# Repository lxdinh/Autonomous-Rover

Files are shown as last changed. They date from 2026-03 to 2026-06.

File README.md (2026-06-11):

# Autonomous Navigation Rover






**🏆 1st Place — UCSD ECE Design Competition (Nov–Dec 2025)** · fastest pathfinding of 13 teams

> Vision-guided autonomous ground rover on a custom ESP32-S3 PCB. An ArduCAM
> OV2640 camera runs on-board RGB565 obstacle detection, an MPU6050 IMU damps the
> heading, and an L298N H-bridge drives the wheels — coordinated by a lightweight
> **FORWARD → STOP → AVOID** state machine. Everything runs on the
> microcontroller.

## Highlights

- **Custom 2-layer, 4×4 in PCB** (KiCad) integrating the ESP32-S3, OV2640,
  MPU6050, and L298N with a shared logic/motor power tree — schematic and
  Gerbers in [`hardware/`](hardware/).
- **From-scratch bare-metal drivers**, no vendor HAL: custom I²C (MPU6050),
  SPI-FIFO (ArduCAM), and LEDC-PWM (L298N) classes — 600+ lines of C++.
- **On-board vision:** per-frame red-blob detection over the middle image band,
  feeding a deterministic navigation state machine.

## Architecture

```mermaid
flowchart LR
  subgraph Sensing
    CAM[OV2640 camera<br/>SPI FIFO] --> DET[Red-blob detector<br/>RGB565, middle band]
    IMU[MPU6050<br/>I2C] --> YAW[Yaw-rate filter]
  end
  DET --> SM[Nav state machine<br/>FORWARD / STOP / AVOID]
  YAW --> MIX[Tank-drive mixer]
  SM --> MIX
  MIX --> MOT[L298N H-bridge<br/>LEDC PWM] --> W[Wheels]
```

### Navigation state machine

```mermaid
stateDiagram-v2
  [*] --> FORWARD
  FORWARD --> STOP: red band >= 20%
  STOP --> AVOID: held 200 ms and still blocked
  STOP --> FORWARD: obstacle cleared
  AVOID --> FORWARD: blob out of view
```

## Repository layout

```text
Autonomous-Rover/
├── src/
│   ├── main.cpp            # nav state machine + obstacle detection + cruise mixer
│   ├── Camera_SPI.h        # ArduCAM OV2640 over SPI FIFO (DMA buffer, BMP/RGB565)
│   ├── Sensor_I2C.h        # MPU6050 IMU (accel/gyro), bare-metal I2C
│   └── MotorDriver_PWM.h   # L298N via ESP32 LEDC PWM (Arduino core 2.x/3.x aware)
├── include/memorysaver.h   # ArduCAM camera-model selector (OV2640 Mini 2MP)
├── hardware/               # KiCad project, schematic (SVG), Gerbers
├── platformio.ini
└── README.md
```

## Hardware

| Subsystem | Part | Interface |
| --- | --- | --- |
| MCU | ESP32-S3 (DevKitC-1 class) | — |
| Camera | ArduCAM OV2640 Mini 2MP | SPI FIFO + I²C control |
| IMU | MPU6050 (accel + gyro) | I²C @ `0x68` |
| Motor driver | L298N dual H-bridge | 6 GPIO (2 PWM enables + 4 direction) |
| Power | 9 V motor pack + 3.3 V logic | common ground |

### Pin map (ESP32-S3)

| Function | GPIO | | Function | GPIO |
| --- | --- | --- | --- | --- |
| L298N ENA — left PWM | 40 | | I²C SDA | 15 |
| L298N ENB — right PWM | 39 | | I²C SCL | 17 |
| L298N IN1 / IN2 — left dir | 44 / 43 | | SPI SCK | 12 |
| L298N IN3 / IN4 — right dir | 42 / 41 | | SPI MISO | 13 |
| Camera CS | 10 | | SPI MOSI | 11 |

### Schematic

Rover schematic

## How obstacle detection works

Each captured frame is RGB565 (one 16-bit value per pixel). The detector scans
the **middle horizontal third** of the frame — where a head-on obstacle sits —
and flags a pixel as "red" when:

| Channel | Bits | Rule |
| --- | --- | --- |
| Red | 5 (0–31) | ≥ 22 |
| Green | 6 (0–63) | ≤ 14 |
| Blue | 5 (0–31) | ≤ 14 |

If **≥ 20 %** of the band's pixels pass, the frame is treated as blocked and the
state machine reacts. All thresholds are compile-time constants in
[`src/main.cpp`](src/main.cpp) — retune `RED_MIN_5BIT`, `GREEN_MAX_6BIT`,
`BLUE_MAX_5BIT`, and `DETECTION_THRESHOLD_PERCENT` for your obstacle color and
lighting.

## Build & flash

Built with **[PlatformIO](https://platformio.org/)** (ESP32-S3 / Arduino
framework). The ArduCAM library is pulled from the PlatformIO registry
automatically; the camera model is selected via the `-DOV2640_MINI_2MP` build
flag in [`platformio.ini`](platformio.ini).

```bash
# from the repo root
pio run                        # compile
pio run -t upload              # flash (board on its native USB port)
pio device monitor -b 115200   # serial @ 115200
```

**Arduino IDE** users: install the **ArduCAM** library, provide a `memorysaver.h`
with `#define OV2640_MINI_2MP`, select an ESP32-S3 board with **USB CDC On Boot:
Enabled**, and build `src/main.cpp`.

## Design notes & tuning

- **Motor duty is capped** to `MOTOR_MAX_DUTY_PCT` (85 %) so that simultaneous
  acceleration on a sagging 9 V pack does not brown out the 3.3 V logic rail.
- **Camera resolution is read from the BMP header** on every capture, so the
  pipeline is robust to QVGA/QCIF differences across ArduCAM firmware revisions.
- **Heading hold:** the MPU6050 yaw-rate currently applies gentle equal-wheel
  damping. Promoting it to a *differential* correction (opposite sign per wheel)
  is the natural next step for tighter straight-line tracking; the mixer already
  exposes a symmetric correction term to build on.

## License

MIT — see [LICENSE](LICENSE). Firmware and hardware authored for the UCSD ECE
Design Competition.

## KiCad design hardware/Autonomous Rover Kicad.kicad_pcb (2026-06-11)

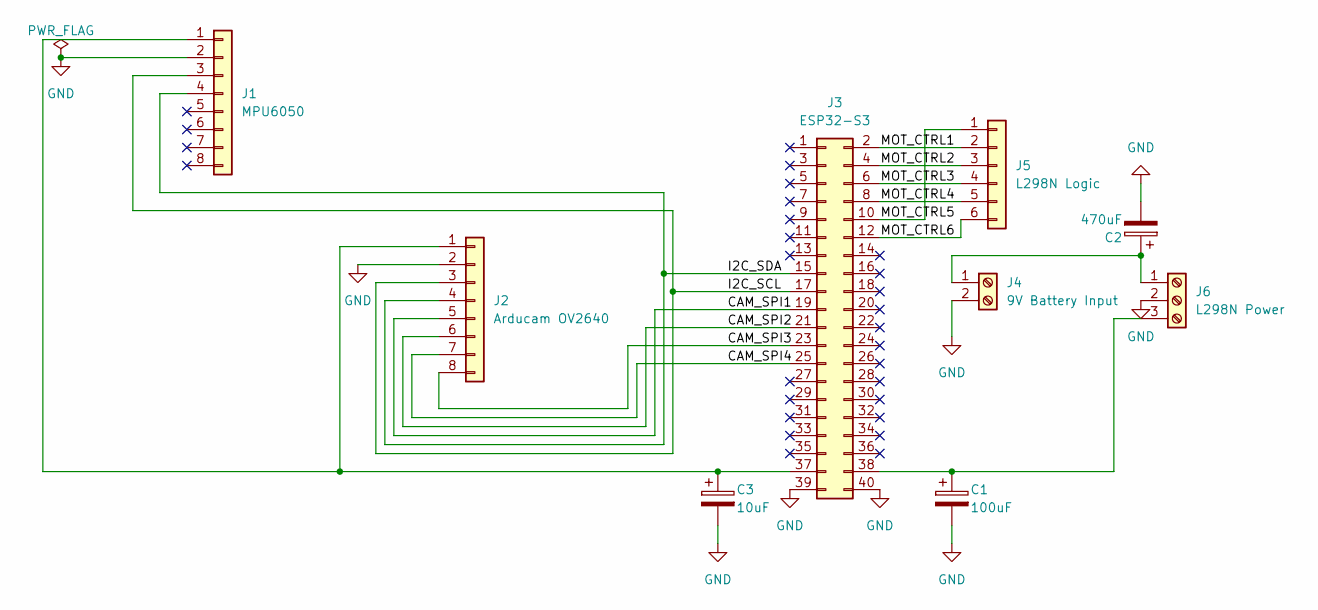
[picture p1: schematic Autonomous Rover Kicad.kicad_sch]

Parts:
C1: 100uF; CP_Radial_D6.3mm_P2.50mm
C2: 470uF; CP_Radial_D8.0mm_P3.50mm
C3: 10uF; CP_Radial_D5.0mm_P2.50mm
J1: MPU6050; PinHeader_1x08_P2.54mm_Vertical
J2: Arducam OV2640; PinHeader_1x08_P2.54mm_Vertical
J3: ESP32-S3; PinHeader_2x20_P2.54mm_Vertical
J4: 9V Battery Input; TerminalBlock_Phoenix_PT-1,5-2-3.5-H_1x02_P3.50mm_Horizontal
J5: L298N Logic; PinHeader_1x06_P2.54mm_Vertical
J6: L298N Power; TerminalBlock_Phoenix_PT-1,5-3-3.5-H_1x03_P3.50mm_Horizontal

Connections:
/CAM_SPI1: J2.5, J3.19
/CAM_SPI2: J2.6, J3.21
/CAM_SPI3: J2.8, J3.23
/CAM_SPI4: J2.7, J3.25
/I2C_SCL: J1.3, J2.3, J3.17
/I2C_SDA: J1.4, J2.4, J3.15
/MOT_CTRL1: J3.2, J5.2
/MOT_CTRL2: J3.4, J5.3
/MOT_CTRL3: J3.6, J5.4
/MOT_CTRL4: J3.8, J5.5
/MOT_CTRL5: J3.10, J5.1
/MOT_CTRL6: J3.12, J5.6
GND: C1.2, C2.2, C3.2, J1.2, J2.2, J3.39, J3.40, J4.2, J6.2
unnamed: C3.1, J1.1, J2.1, J3.37
unnamed: C1.1, J3.38, J6.3
unnamed: C2.1, J4.1, J6.1

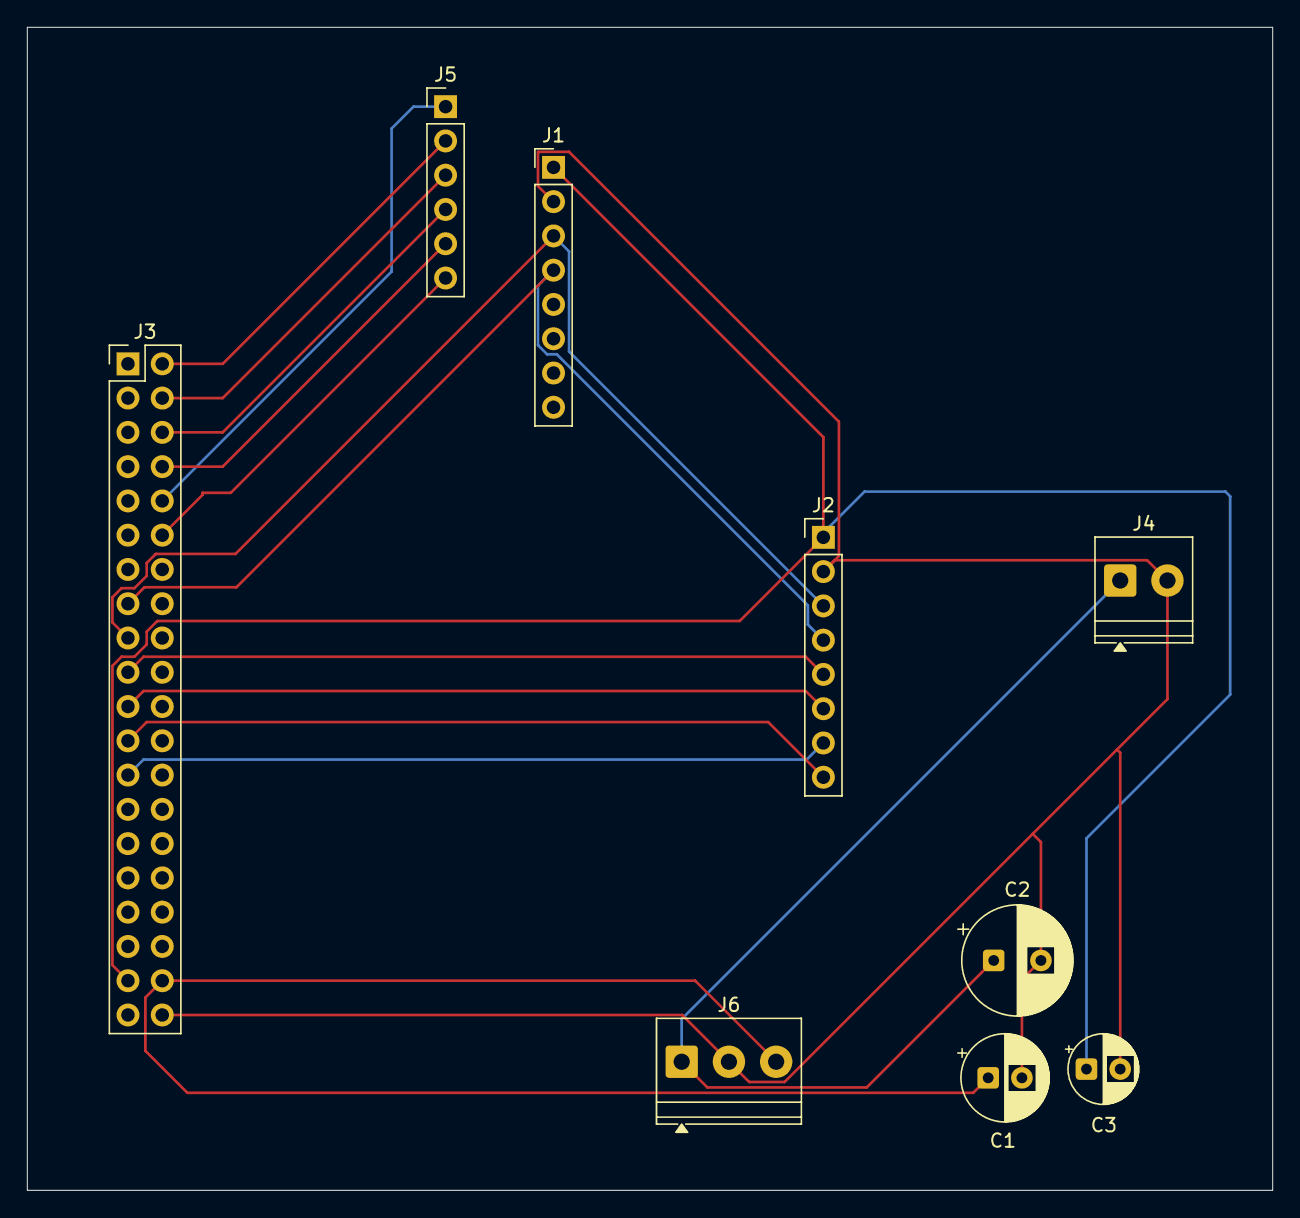
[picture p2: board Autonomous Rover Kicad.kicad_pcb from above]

Board: 2 copper layers, 92.3 x 86.2 mm, 9 parts (0 on the bottom side), 16 nets.

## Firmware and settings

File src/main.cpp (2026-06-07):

/**
 * ESP32-S3 rover — camera obstacle avoidance using ArduCAM OV2640 (SPI FIFO + I2C sensor).
 * Wire @ SDA/SCL talks to MPU6050 (0x68) and OV2640 regs through the ArduCAM bridge;
 * SPI pushes CS low and bursts pixel data from the camera FIFO after each capture.
 */

#include <Arduino.h>

#if defined(CONFIG_IDF_TARGET_ESP32S3) || defined(ARDUINO_ESP32S3_DEV) || \
    defined(ARDUINO_ESP32S3)
#include <driver/gpio.h>
#endif

#include <SPI.h>
#include <Wire.h>

#include "MotorDriver_PWM.h"
#include "Sensor_I2C.h"
#include "Camera_SPI.h"

// --- Pins (KiCad / ESP32-S3) ---
static const uint8_t PIN_IN1 = 44;
static const uint8_t PIN_IN2 = 43;
static const uint8_t PIN_IN3 = 42;
static const uint8_t PIN_IN4 = 41;
static const uint8_t PIN_ENA = 40;
static const uint8_t PIN_ENB = 39;
static const uint8_t PIN_SDA = 15;
static const uint8_t PIN_SCL = 17;
static const uint8_t PIN_SCK = 12;
static const uint8_t PIN_MISO = 13;
static const uint8_t PIN_MOSI = 11;
static const uint8_t PIN_CAM_CS = 10;

// --- Obstacle detection (RGB565 "red blob" in middle horizontal band) ---
// Each pixel is 16 bits: 5 bits R, 6 bits G, 5 bits B (no separate bytes — packed in one uint16).
#define DETECTION_THRESHOLD_PERCENT 20  // call it an obstacle if >= this % of band pixels look "red"
#define RED_MIN_5BIT 22                 // R must be at least this (0–31 scale)
#define GREEN_MAX_6BIT 14               // G must be at most this (0–63 scale)
#define BLUE_MAX_5BIT 14                // B must be at most this (0–31 scale)

// --- Driving / timing ---
static const int16_t CRUISE_BASE_SPEED = 130;
static const int16_t TURN_LEFT_WHEEL = 150;
static const int16_t TURN_RIGHT_WHEEL = -150;
static const uint32_t SENSOR_MS = 20;
static const uint32_t OBSTACLE_CHECK_MS = 40;
static const uint32_t SERIAL_STATUS_MS = 400;
// Don't print faster than this — still feels "live" but won't overwhelm Serial Monitor.
static const uint32_t CAMERA_DEBUG_MIN_MS = 150;
// How long we sit in STOP (motors off) before we start AVOID turn — easy to show on demo day.
static const uint32_t STOP_HOLD_MS = 200;

SensorI2C imu(PIN_SDA, PIN_SCL);
MotorDriverPWM motors(PIN_ENA, PIN_ENB, PIN_IN1, PIN_IN2, PIN_IN3, PIN_IN4);
CameraSPI cam(PIN_CAM_CS);

uint32_t lastSens = 0;
uint32_t lastObs = 0;
uint32_t lastSerial = 0;
uint32_t lastCameraPrint = 0;

float yawRateFiltered = 0.0f;

// Navigation state machine (FORWARD -> STOP -> AVOID -> FORWARD)
enum RoverState : uint8_t { STATE_FORWARD = 0, STATE_STOP = 1, STATE_AVOID = 2 };
static RoverState roverState = STATE_FORWARD;
static uint32_t stopStateEnteredMs = 0;

bool isObstacleDetected = false;
static float lastRedBandPercent = 0.0f;  // for Serial debug

static int16_t computeLeft(int16_t base, float brightnessErr, float yawDps) {
  int32_t v = base + (int32_t)(brightnessErr * 0.8f) - (int32_t)(yawDps * 6.0f);
  if (v > 200) v = 200;
  if (v < -200) v = -200;
  return (int16_t)v;
}

static int16_t computeRight(int16_t base, float brightnessErr, float yawDps) {
  int32_t v = base - (int32_t)(brightnessErr * 0.8f) - (int32_t)(yawDps * 6.0f);
  if (v > 200) v = 200;
  if (v < -200) v = -200;
  return (int16_t)v;
}

/**
 * Grab one frame from the ArduCAM FIFO (SPI), then count "red-looking" pixels in the
 * middle horizontal band (middle third of rows). Returns false if capture failed.
 *
 * RGB565 math (one 16-bit value per pixel):
 *   bits 15..11 -> Red   (5 bits): shift right by 11, then mask 0x1F
 *   bits 10..5  -> Green (6 bits): shift right by 5,  mask 0x3F
 *   bits 4..0   -> Blue  (5 bits): mask 0x1F (no shift)
 * We compare those to RED_MIN / GREEN_MAX / BLUE_MAX to catch "mostly red" obstacles.
 */
bool detectObstacle(CameraSPI &camera, bool &outObstacle, float &outRedPercent) {
  outObstacle = false;
  outRedPercent = 0.0f;

  if (!camera.captureFrameQCIF_DMA()) {
    Serial.println("[detectObstacle] FIFO capture failed");
    return false;
  }

  const uint16_t *pixels = (const uint16_t *)camera.frameBuffer();
  uint16_t imgW = camera.width();
  uint16_t imgH = camera.height();
  if (!pixels || imgW == 0 || imgH < 3) {
    return false;
  }

  // Middle horizontal band: rows [H/3 .. 2H/3) — where we expect obstacles in front of the rover.
  uint16_t rowStart = imgH / 3;
  uint16_t rowEnd = (2u * imgH) / 3;

  uint32_t redCount = 0;
  uint32_t totalInBand = 0;

  for (uint16_t y = rowStart; y < rowEnd; y++) {
    const uint16_t *row = pixels + (size_t)y * imgW;
    for (uint16_t x = 0; x < imgW; x++) {
      uint16_t p = row[x];
      // Split RGB565 into R, G, B using the bit layout above.
      uint8_t r = (uint8_t)((p >> 11) & 0x1F);
      uint8_t g = (uint8_t)((p >> 5) & 0x3F);
      uint8_t b = (uint8_t)(p & 0x1F);

      totalInBand++;
      if (r >= RED_MIN_5BIT && g <= GREEN_MAX_6BIT && b <= BLUE_MAX_5BIT) {
        redCount++;
      }
    }
  }

  float pct = 0.0f;
  if (totalInBand > 0) {
    pct = 100.0f * (float)redCount / (float)totalInBand;
  }
  outRedPercent = pct;
  outObstacle = (pct >= (float)DETECTION_THRESHOLD_PERCENT);
  return true;
}

#if defined(CONFIG_IDF_TARGET_ESP32S3) || defined(ARDUINO_ESP32S3_DEV) || \
    defined(ARDUINO_ESP32S3)
static void roverPrepareL298nGpio(void) {
  gpio_reset_pin((gpio_num_t)PIN_ENB);
  gpio_reset_pin((gpio_num_t)PIN_ENA);
  gpio_reset_pin((gpio_num_t)PIN_IN4);
  gpio_reset_pin((gpio_num_t)PIN_IN3);
  gpio_reset_pin((gpio_num_t)PIN_IN2);
  gpio_reset_pin((gpio_num_t)PIN_IN1);
}
#endif

void setup() {
  Serial.begin(115200);
  delay(300);
  Serial.println("\n=== rover boot (ArduCAM obstacle + state machine) ===");

#if defined(CONFIG_IDF_TARGET_ESP32S3) || defined(ARDUINO_ESP32S3_DEV) || \
    defined(ARDUINO_ESP32S3)
  roverPrepareL298nGpio();
#endif

  // Shared I2C bus: MPU6050 @ 0x68, OV2640 sensor regs via ArduCAM @ 0x30 (7-bit addresses).
  Wire.begin(PIN_SDA, PIN_SCL);
  if (!imu.begin()) {
    Serial.println("IMU init failed");
  }

  SPI.begin(PIN_SCK, PIN_MISO, PIN_MOSI, PIN_CAM_CS);
  if (!cam.begin()) {
    Serial.println("[fatal] camera init failed");
  }

  motors.begin();

  Serial.println("States: FORWARD -> STOP (red >= threshold) -> AVOID (turn) -> FORWARD");
}

void loop() {
  uint32_t now = millis();

  if (now - lastSens >= SENSOR_MS) {
    lastSens = now;
    float gz = imu.gyroZdps();
    yawRateFiltered = 0.85f * yawRateFiltered + 0.15f * gz;
  }

  if (now - lastObs >= OBSTACLE_CHECK_MS) {
    lastObs = now;
    bool obs = false;
    float redPct = 0.0f;
    if (detectObstacle(cam, obs, redPct)) {
      isObstacleDetected = obs;
      lastRedBandPercent = redPct;

      if (now - lastCameraPrint >= CAMERA_DEBUG_MIN_MS) {
        lastCameraPrint = now;
        Serial.print("Camera: red pixels ~ ");
        Serial.print(redPct, 1);
        Serial.print("% (threshold ");
        Serial.print(DETECTION_THRESHOLD_PERCENT);
        Serial.println("%)  ");
      }

      if (obs && roverState == STATE_FORWARD) {
        roverState = STATE_STOP;
        stopStateEnteredMs = now;  // use the loop's timestamp; a fresh millis()
                                   // here is > now and underflows the unsigned
                                   // (now - stopStateEnteredMs) hold check below.
        Serial.println("State -> STOP (cut motors briefly)");
      }
    }
  }

  float err = 0.0f;
  int16_t leftCruise = computeLeft(CRUISE_BASE_SPEED, err, yawRateFiltered);
  int16_t rightCruise = computeRight(CRUISE_BASE_SPEED, err, yawRateFiltered);

  switch (roverState) {
    case STATE_FORWARD:
      motors.setTankDrive(leftCruise, rightCruise);
      break;

    case STATE_STOP:
      motors.stop();
      if (!isObstacleDetected) {
        roverState = STATE_FORWARD;
        Serial.println("State -> FORWARD (obstacle cleared while stopped)");
      } else if ((now - stopStateEnteredMs) >= STOP_HOLD_MS) {
        roverState = STATE_AVOID;
        Serial.println("State -> AVOID (turn right to get blob out of view)");
      }
      break;

    case STATE_AVOID:
      motors.setTankDrive(TURN_LEFT_WHEEL, TURN_RIGHT_WHEEL);
      if (!isObstacleDetected) {
        roverState = STATE_FORWARD;
        Serial.println("State -> FORWARD (blob gone)");
      }
      break;

    default:
      roverState = STATE_FORWARD;
      break;
  }

  if (now - lastSerial >= SERIAL_STATUS_MS) {
    lastSerial = now;
    Serial.print("[nav] state=");
    switch (roverState) {
      case STATE_FORWARD:
        Serial.print("FORWARD");
        break;
      case STATE_STOP:
        Serial.print("STOP");
        break;
      case STATE_AVOID:
        Serial.print("AVOID");
        break;
      default:
        Serial.print("?");
        break;
    }
    Serial.print("  lastRed=");
    Serial.print(lastRedBandPercent, 1);
    Serial.println("%");
  }
}

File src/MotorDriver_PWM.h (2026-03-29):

/**
 * MotorDriver_PWM.h
 * Simple L298N wrapper for ESP32 LEDC PWM on enable pins.
 * IN pins are digital; ENA/ENB use LEDC only (never analogWrite()).
 *
 * Core 2.x: ledcSetup + ledcAttachPin + ledcWrite(channel).
 * Core 3.x: ledcAttach(pin) + ledcWrite(pin) — picked automatically via esp_arduino_version.h.
 *
 * ESP32-S3: GPIO39–44 are valid outputs; ENA/ENB get normal LEDC PWM (no dedicated
 * “motor” pins). Note: GPIO39–42 are the chip’s default JTAG (MTCK/MTDO/MTDI/MTMS);
 * with motors on those nets, turn off JTAG in firmware or your debugger may fight
 * the L298N. IN1/IN2 on 43–44 are outside that block.
 *
 * NOTE: Duty is scaled assuming a ~9V nominal battery pack. Fresh cells read
 * higher (~9.6V) but under load the pack sags — we cap effective PWM so the
 * motors don't brown out the ESP32 rail when both sides spike. Tune MAX_DUTY_PCT.
 */
#ifndef MOTOR_DRIVER_PWM_H
#define MOTOR_DRIVER_PWM_H

#include <Arduino.h>

#ifndef __has_include
#define __has_include(x) 0
#endif
#if __has_include("esp_arduino_version.h")
#include "esp_arduino_version.h"
#endif

// Arduino-ESP32 3.0+ uses pin-based LEDC; 2.x uses channel + ledcAttachPin.
#if defined(ESP_ARDUINO_VERSION_MAJOR) && (ESP_ARDUINO_VERSION_MAJOR >= 3)
#define MOTOR_LEDC_USE_PIN_API 1
#else
#define MOTOR_LEDC_USE_PIN_API 0
#endif

// 9V pack: leave headroom so simultaneous accel doesn't dip logic supply too hard
#ifndef MOTOR_MAX_DUTY_PCT
#define MOTOR_MAX_DUTY_PCT 85  // percent of LEDC resolution range
#endif

class MotorDriverPWM {
 public:
  MotorDriverPWM(uint8_t pinEnA, uint8_t pinEnB, uint8_t pinIn1, uint8_t pinIn2,
                 uint8_t pinIn3, uint8_t pinIn4, uint32_t pwmFreqHz = 5000,
                 uint8_t pwmBits = 8)
      : _ena(pinEnA),
        _enb(pinEnB),
        _in1(pinIn1),
        _in2(pinIn2),
        _in3(pinIn3),
        _in4(pinIn4),
        _freq(pwmFreqHz),
        _bits(pwmBits),
        _chA(0),
        _chB(1) {}

  void begin() {
    pinMode(_in1, OUTPUT);
    pinMode(_in2, OUTPUT);
    pinMode(_in3, OUTPUT);
    pinMode(_in4, OUTPUT);

    pwmAttachEnables();

#if MOTOR_LEDC_USE_PIN_API
    Serial.println("[MotorDriver] L298N PWM: core 3.x (ledcAttach + ledcWrite pin)");
#else
    Serial.println("[MotorDriver] L298N PWM: core 2.x (ledcSetup + ledcAttachPin + channel)");
#endif

    stop();
  }

  /** speed: -255..255-ish, sign = direction */
  void setLeftMotor(int16_t speed) {
    bool fwd = speed >= 0;
    uint16_t mag = (uint16_t)abs(speed);
    mag = scaleDuty(mag);
    digitalWrite(_in1, fwd ? HIGH : LOW);
    digitalWrite(_in2, fwd ? LOW : HIGH);
    pwmWriteEna(mag);
  }

  void setRightMotor(int16_t speed) {
    bool fwd = speed >= 0;
    uint16_t mag = (uint16_t)abs(speed);
    mag = scaleDuty(mag);
    digitalWrite(_in3, fwd ? HIGH : LOW);
    digitalWrite(_in4, fwd ? LOW : HIGH);
    pwmWriteEnb(mag);
  }

  void setTankDrive(int16_t left, int16_t right) {
    setLeftMotor(left);
    setRightMotor(right);
  }

  void stop() {
    digitalWrite(_in1, LOW);
    digitalWrite(_in2, LOW);
    digitalWrite(_in3, LOW);
    digitalWrite(_in4, LOW);
    pwmWriteEna(0);
    pwmWriteEnb(0);
  }

 private:
  uint8_t _ena, _enb, _in1, _in2, _in3, _in4;
  uint32_t _freq;
  uint8_t _bits;
  uint8_t _chA, _chB;  // legacy core: LEDC channel indices for ENA/ENB

  void pwmAttachEnables() {
#if MOTOR_LEDC_USE_PIN_API
    if (!ledcAttach(_ena, (double)_freq, _bits)) {
      Serial.println("[MotorDriver] ledcAttach ENA failed");
    }
    if (!ledcAttach(_enb, (double)_freq, _bits)) {
      Serial.println("[MotorDriver] ledcAttach ENB failed");
    }
#else
    ledcSetup(_chA, _freq, _bits);
    ledcSetup(_chB, _freq, _bits);
    ledcAttachPin(_ena, _chA);
    ledcAttachPin(_enb, _chB);
#endif
  }

  void pwmWriteEna(uint16_t duty) {
#if MOTOR_LEDC_USE_PIN_API
    ledcWrite(_ena, duty);
#else
    ledcWrite(_chA, duty);
#endif
  }

  void pwmWriteEnb(uint16_t duty) {
#if MOTOR_LEDC_USE_PIN_API
    ledcWrite(_enb, duty);
#else
    ledcWrite(_chB, duty);
#endif
  }

  uint16_t scaleDuty(uint16_t raw) {
    uint32_t maxVal = (1u << _bits) - 1u;
    uint32_t cap = (maxVal * (uint32_t)MOTOR_MAX_DUTY_PCT) / 100u;
    if (raw > maxVal) raw = (uint16_t)maxVal;
    uint32_t out = (raw * cap) / maxVal;
    return (uint16_t)out;
  }
};

#endif

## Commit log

2026-03-29 Initial release
    [Autonomous Rover Kicad-B_Cu.gbr, Autonomous Rover Kicad-B_Mask.gbr, Autonomous Rover Kicad-B_Paste.gbr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]
2026-03-29 Embed schematic image into README
2026-06-07 Fix firmware build + harden project (CI, docs, license)
    The committed firmware did not compile; it now builds clean for the ESP32-S3,
    verified locally with `pio run` (RAM 6.2%, Flash 9.2%).
    - Camera_SPI.h: make pixelDataPtr() const so the const frameBuffer() overload
    compiles. This was a hard error (passing 'const CameraSPI' as 'this' discards
    qualifiers) that broke the entire build on a standard PlatformIO toolchain.
    - main.cpp: fix unsigned underflow in the FORWARD->STOP hold timer. It set
    stopStateEnteredMs with a fresh millis() taken after `now`, so
    (now - stopStateEnteredMs) underflowed and the rover skipped its 200 ms stop
    and jumped straight to AVOID. Use the loop's `now` t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
    [Camera_SPI.h, main.cpp]
2026-06-11 Clean up schematic: ERC 0, net labels, decoupling caps
    KiCad ERC now passes with 0 violations (was 29 - all unannotated unused pins
    plus a missing power flag), verified with kicad-cli 9.0.
    - Add no-connect flags to the 28 intentionally-unused module pins (MPU6050
    J1.5-8 and the unused ESP32/J3 GPIOs).
    - Add a PWR_FLAG on GND so ERC knows the rail is externally powered.
    - Name the nets: +5V, +3V3, VMOTOR, I2C_SDA, I2C_SCL, CAM_SPI1-4,
    MOT_CTRL1-6 (were auto-named Net-Jx-Pin_y).
    - Add bulk decoupling: C1 100uF on +5V, C2 470uF on VMOTOR, C3 10uF on +3V3
    to harden against motor-transient brownouts (the same risk the firmware
    PWM duty cap guards against). Connectivity confirmed via netl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
    [Autonomous Rover Kicad.kicad_sch]
2026-06-11 Caps: use polarized C_Polarized symbol + assign THT footprints
    - C1 100uF (+5V) -> Capacitor_THT:CP_Radial_D6.3mm_P2.50mm
    - C2 470uF (VMOTOR) -> Capacitor_THT:CP_Radial_D8.0mm_P3.50mm
    - C3 10uF (+3V3) -> Capacitor_THT:CP_Radial_D5.0mm_P2.50mm
    Pin 1 (+) stays on the rail, pin 2 (-) on GND. Verified with kicad-cli: ERC 0,
    netlist confirms the polarized symbol and footprints. The large line diff is
    mostly KiCad re-save formatting from the prior editing session.
    [Autonomous Rover Kicad.kicad_sch]
2026-06-11 Hardware: bring decoupling caps onto the PCB + refresh schematic image
    - PCB: C1/C2/C3 placed and routed, copper pour updated. Verified with
    kicad-cli: DRC 0 violations, 0 unconnected items.
    - Replace the stale Schematic.png with an up-to-date Schematic.svg that shows
    the net labels, no-connect flags, and the three decoupling caps; README now
    points to the SVG (opaque light background, renders in light and dark themes).
    - gitignore KiCad editor lock files.
    [Autonomous Rover Kicad.kicad_pcb]
